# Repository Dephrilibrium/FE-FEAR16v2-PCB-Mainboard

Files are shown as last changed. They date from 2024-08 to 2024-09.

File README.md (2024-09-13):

# FEAR-Mainboard
This repository contains the KiCAD-design files of the F(ield) E(mission) A(rray) R(egulation) current control circuit board.

Note: This project is part of the SubModule-repository [FE-FEAR16v2][FE-FEAR16v2-SubmoduleRepo], where you can find sub-repositories for shield-PCBs and the firmware.

# Description
The board has two areas. A low-voltage side (5V USB for computer connection, top left) which is galvanically isolated up to 1500V from the high voltage side (rest of the PCB).

The board uses a USB-C jack on the low-voltage side of the board for communication. The USB-C can also be used as AC power supply, but for this, a USB-Hub with an AC-power adapter is recommended (depending on the amount of shields and their power-use). Alternatively, a 12V screw-terminal is added as option for an external 12V AC power supply. The option if 5V USB or 12V external supply is selected by a solder-jumper. (Note: +5V or +12V needs different DCDC converter types for the +-15V supply voltage on the high-voltage side!)

The board communicates via USB by providing a virtual COM-Port on the computer. The serial connection from the FT232 for board-internal communication is transferred from the low-voltage side to the high-voltage side via optocouplers and there connected to a TIVA-Launchpad, providing the microcontroller (µC). The Launchpad runs a terminal where you can query different commands e.g. querying measurement values, etc. The µC uses SPI connections for the ADCs and DACs.

ADCs and DACs have different supplies for logic (digital signals) and references (analog) and provide 2 ADC-inputs (VShnt0..15 and VDrp0..15) for measurements and 1x DAC-output (DAC0..15) for controls to each of the shields. Each ADC and DAC has only 8 inputs. Therefore, 2 of them each can be daisy-chained together to achieve 16 in-/outputs for VShnt, VDrp and DAC.

The ADC and DAC range is by default &pm;10V. However, the ranges can be adjusted within the firmware in the ADC/DAC-wrapper sourcecodes.

# Firmware
The board-firmware can be found in the [FE-FEAR16v2 Submodule-Repo][FE-FEAR16v2-SubmoduleRepo] and needs to be flashed onto the µC of the LaunchPad. Instructions and command-documentation can be found in the firmware-repository.

# Daisy-Chains
ADCs and DACs only have 8 In-/Outputs per chip. For enough In-/Outputs for up to 16 shields, 2 ADCs or DACs can be daisy-chained together. 1 and 2 chips per ADC- and DAC-chain were tested. When using only 1 chip per ADC-/DAC-chain, the MISO (SPI data in) and MOSI (SPI data out) pins of the empty ADC-footprint needs to be shorted. The connection is indicated by the silk-screen:
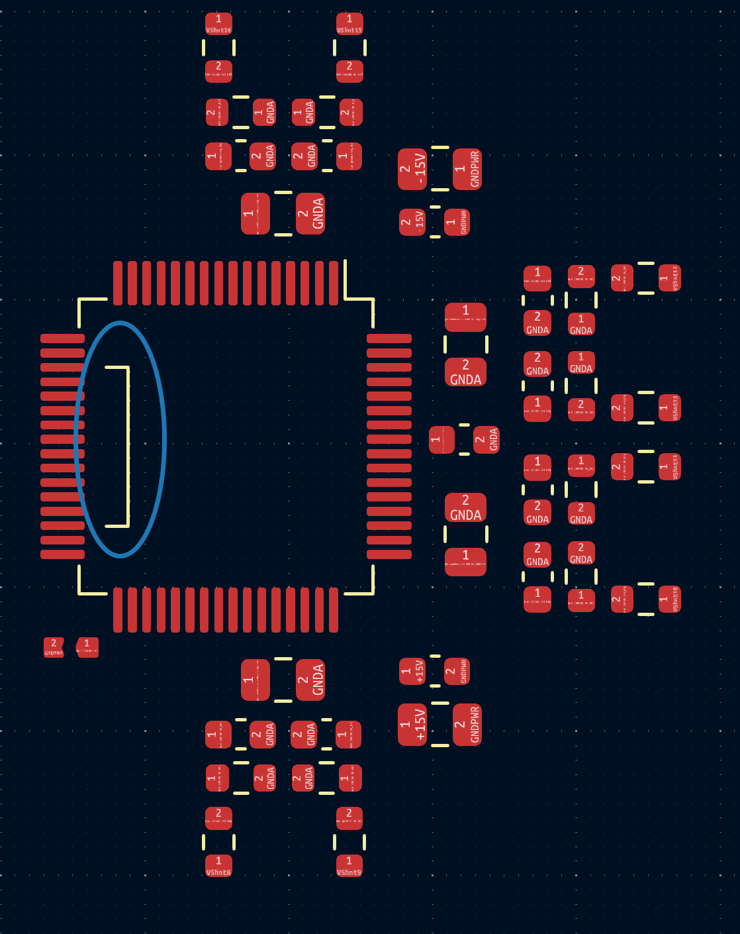
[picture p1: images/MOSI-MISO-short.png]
Principle of the regulation

The firmware handles this via software defines (described in the firmware-repository).

[FE-FEAR16v2-SubmoduleRepo]: https://github.com/Dephrilibrium/FE-FEAR16v2

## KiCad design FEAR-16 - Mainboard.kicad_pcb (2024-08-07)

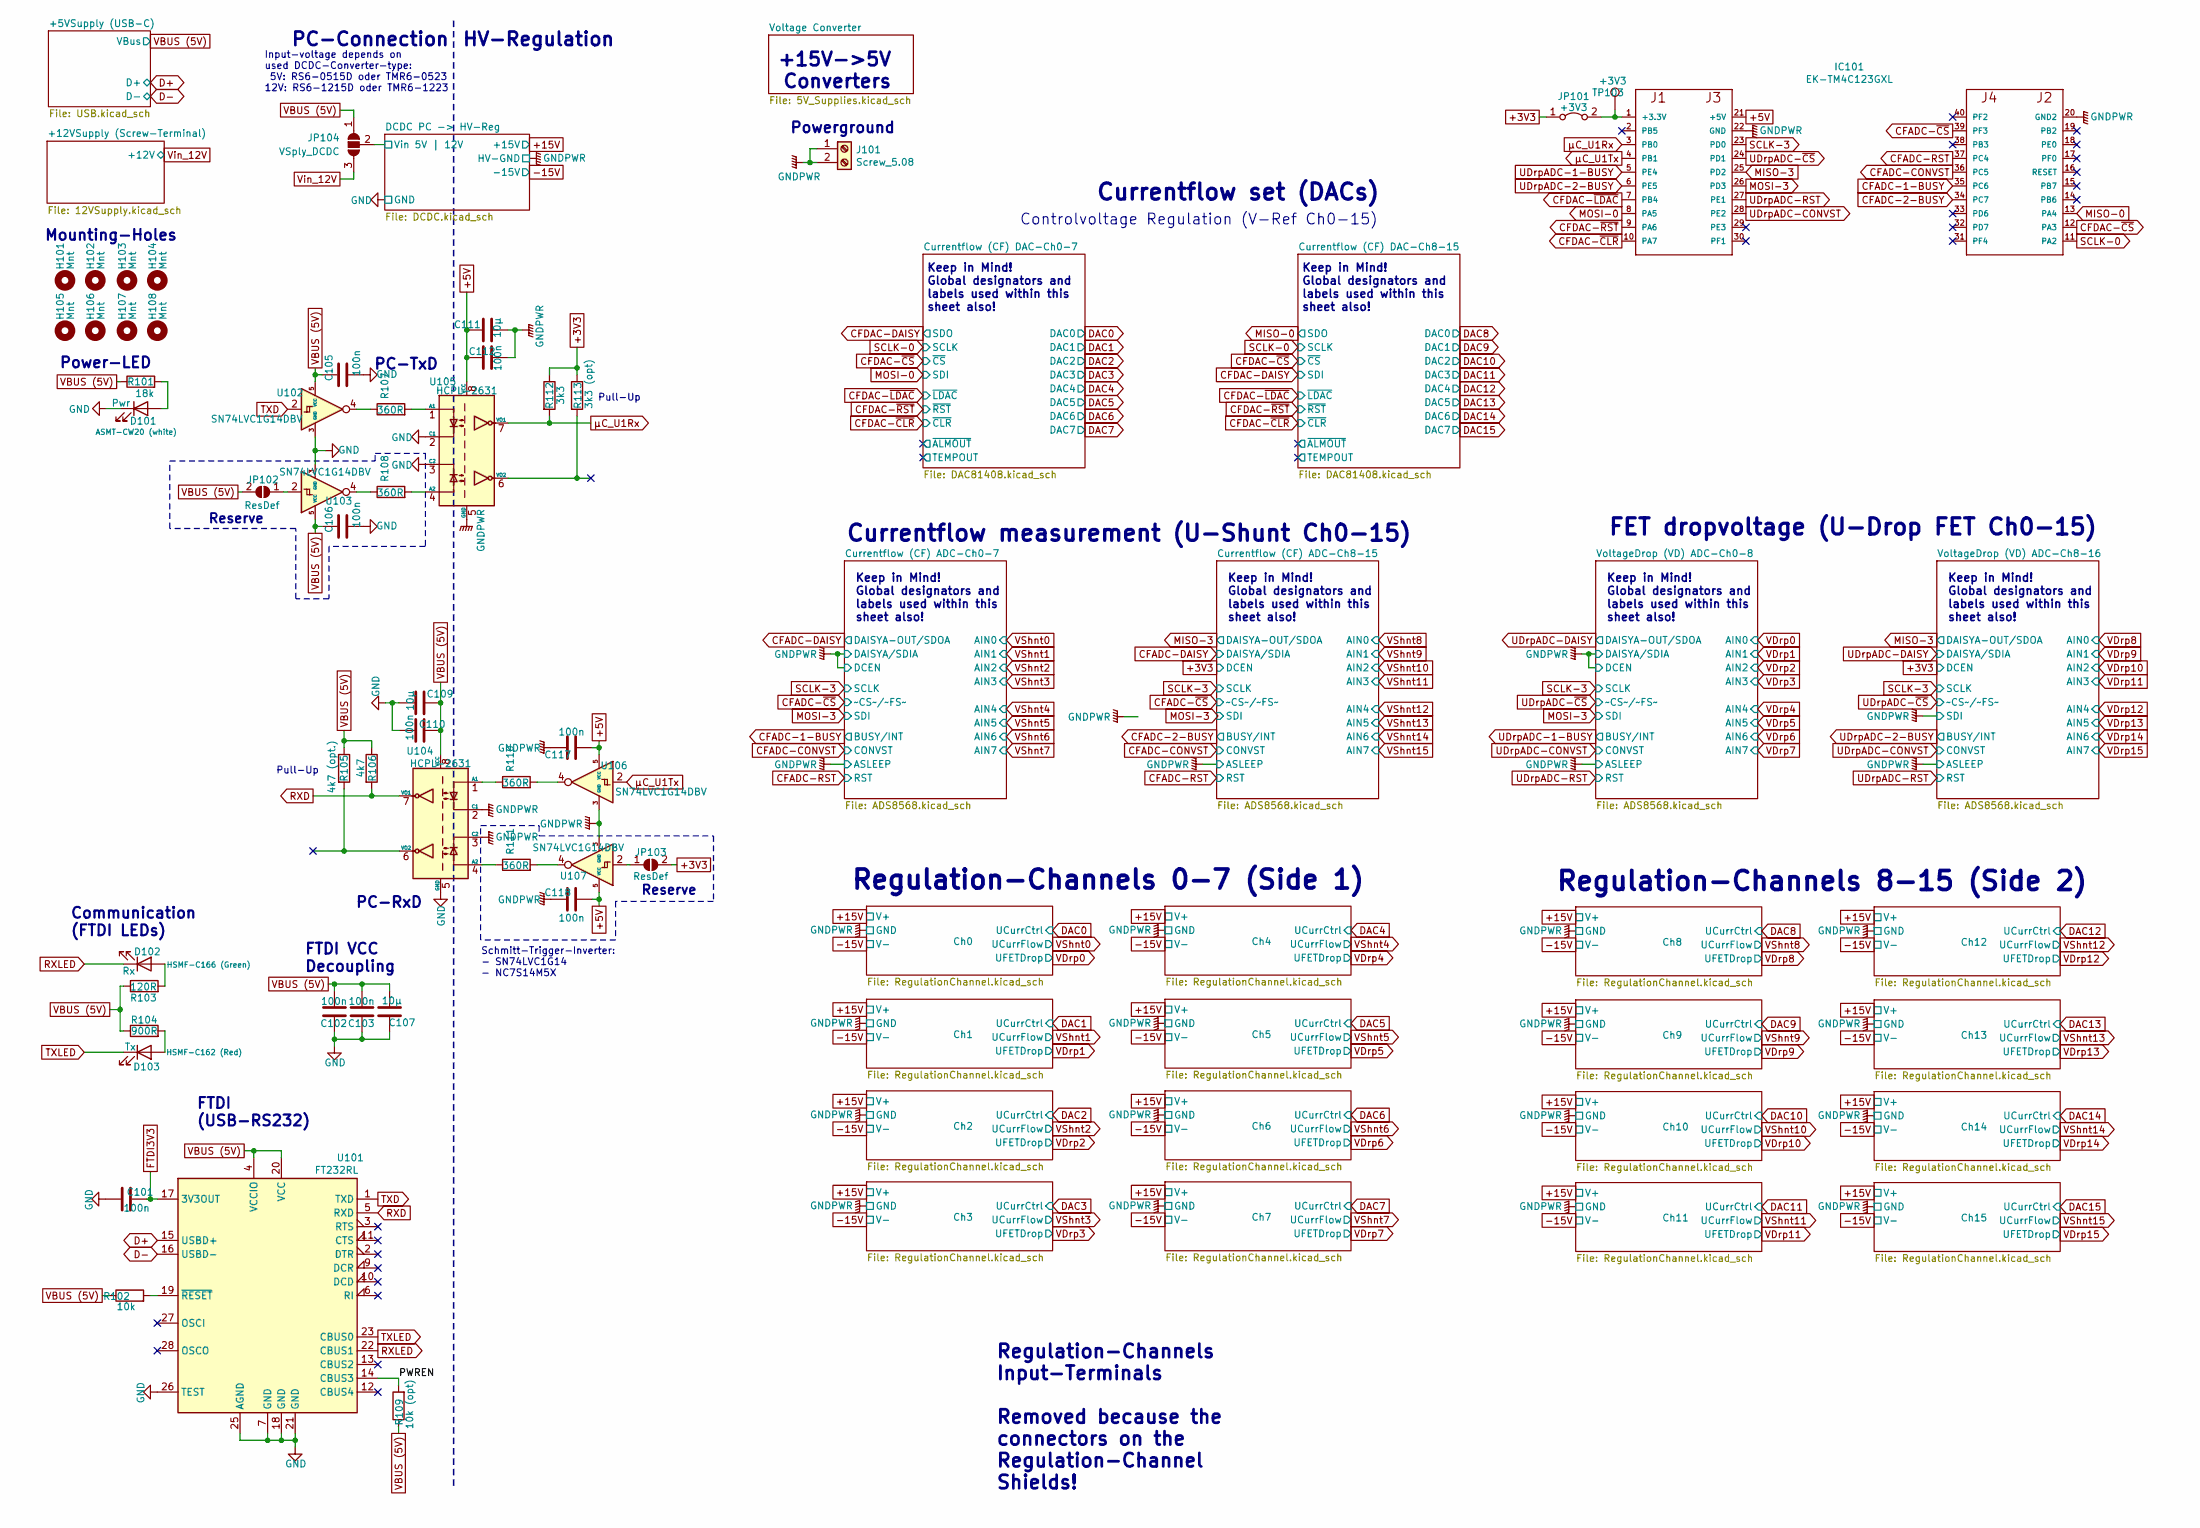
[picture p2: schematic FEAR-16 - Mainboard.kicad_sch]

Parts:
C101, C102, C103, C105, C106, C110, C112, C117, C118: 100n; C_0603_1608Metric
C107, C109, C111: 10µ; C_0805_2012Metric
D101: Pwr; LED_0603_1608Metric
D102: Rx; LED_0603_1608Metric
D103: Tx; LED_0603_1608Metric
H101, H102, H103, H104, H105, H106, H107, H108: Mnt; MountingHole_3.2mm_M3
IC101: EK-TM4C123GXL; TM4C123LAUNCHPAD
J101: Screw_5.08; TerminalBlock_RND_205-00232_1x02_P5.08mm_Horizontal
JP101: +3V3; PinHeader_1x02_P2.54mm_Vertical
JP102, JP103: ResDef; SolderJumper-2_P1.3mm_Open_RoundedPad1.0x1.5mm
JP104: VSply_DCDC; SolderJumper-3_P1.3mm_Open_RoundedPad1.0x1.5mm
R101: 18k; R_0603_1608Metric
R102: 10k; R_0603_1608Metric
R103: 120R; R_0603_1608Metric
R104: 900R; R_0603_1608Metric
R105: 4k7 (opt.); R_0603_1608Metric
R106: 4k7; R_0603_1608Metric
R107, R108, R110, R111: 360R; R_0603_1608Metric
R109: 10k (opt); R_0603_1608Metric
R112: 3k3; R_0603_1608Metric
R113: 3k3 (opt); R_0603_1608Metric
TP103: +3V3; TestPoint_Pad_D1.5mm
U101: FT232RL; SSOP-28_5.3x10.2mm_P0.65mm
U102, U103, U106, U107: SN74LVC1G14DBV; SOT-23-5
U104, U105: HCPL-2631; DIP-8_W7.62mm

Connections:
+3V3: JP101.1 (A), JP103.2 (B), R112.1, R113.1; also elsewhere on the board
+5V: C111.1, C112.2, C117.1, C118.1, IC101.21 (+5V), U105.8 (VCC), U106.5 (VCC), U107.5 (VCC); also elsewhere on the board
/DCDC PC -> HV-Reg/Vin 5V | 12V: JP104.2 (C); also elsewhere on the board
/PWREN: R109.2, U101.14 (CBUS3)
CFADC-1-BUSY: IC101.35 (PC6); also elsewhere on the board
CFADC-2-BUSY: IC101.34 (PC7); also elsewhere on the board
CFADC-CONVST: IC101.36 (PC5); also elsewhere on the board
CFADC-RST: IC101.37 (PC4); also elsewhere on the board
CFADC-~CS: IC101.39 (PF3); also elsewhere on the board
CFDAC-~CLR: IC101.10 (PA7); also elsewhere on the board
CFDAC-~CS: IC101.12 (PA3); also elsewhere on the board
CFDAC-~LDAC: IC101.7 (PB4); also elsewhere on the board
CFDAC-~RST: IC101.9 (PA6); also elsewhere on the board
D+: U101.15 (USBD+); also elsewhere on the board
D-: U101.16 (USBD-); also elsewhere on the board
FTDI3V3: C101.2, U101.17 (3V3OUT)
GND: C101.1, C102.1, C103.1, C105.2, C106.2, C107.2, C109.2, C110.1, D101.1 (K), U101.7 (GND), U101.18 (GND), U101.21 (GND), U101.25 (AGND), U101.26 (TEST), U102.3 (GND), U103.3 (GND), U104.5 (GND), U105.2 (C1), U105.3 (C2); also elsewhere on the board
GNDPWR: C111.2, C112.1, C117.2, C118.2, IC101.20 (GND2), IC101.22 (GND), J101.1, J101.2, U104.2 (C1), U104.3 (C2), U105.5 (GND), U106.3 (GND), U107.3 (GND); also elsewhere on the board
MISO-0: IC101.13 (PA4); also elsewhere on the board
MISO-3: IC101.25 (PD2); also elsewhere on the board
MOSI-0: IC101.8 (PA5); also elsewhere on the board
MOSI-3: IC101.26 (PD3); also elsewhere on the board
unnamed: D101.2 (A), R101.2
unnamed: D102.2 (A), R103.2
unnamed: D103.2 (A), R104.2
unnamed: IC101.1 (+3.3V), JP101.2 (B), TP103.1
unnamed: JP102.1 (A), U103.2
unnamed: JP103.1 (A), U107.2
unnamed: R107.1, U102.4
unnamed: R108.1, U103.4
unnamed: R110.2, U106.4
unnamed: R111.2, U107.4
unnamed: R102.2, U101.19 (~RESET)
unnamed: R110.1, U104.1 (A1)
unnamed: R111.1, U104.4 (A2)
unnamed: R107.2, U105.1 (A1)
unnamed: R108.2, U105.4 (A2)
RXD: R106.2, U101.5 (RXD), U104.7 (VO1)
RXLED: D102.1 (K), U101.22 (CBUS1)
SCLK-0: IC101.11 (PA2); also elsewhere on the board
SCLK-3: IC101.23 (PD0); also elsewhere on the board
TXD: U101.1 (TXD), U102.2
TXLED: D103.1 (K), U101.23 (CBUS0)
UDrpADC-1-BUSY: IC101.5 (PE4); also elsewhere on the board
UDrpADC-2-BUSY: IC101.6 (PE5); also elsewhere on the board
UDrpADC-CONVST: IC101.28 (PE2); also elsewhere on the board
UDrpADC-RST: IC101.27 (PE1); also elsewhere on the board
UDrpADC-~CS: IC101.24 (PD1); also elsewhere on the board
VBUS (5V): C102.2, C103.2, C105.1, C106.1, C107.1, C109.1, C110.2, JP102.2 (B), JP104.1 (A), R101.1, R102.1, R103.1, R104.1, R105.1, R106.1, R109.1, U101.4 (VCCIO), U101.20 (VCC), U102.5 (VCC), U103.5 (VCC), U104.8 (VCC); also elsewhere on the board
Vin_12V: JP104.3 (B); also elsewhere on the board
µC_U1Rx: IC101.3 (PB0), R112.2, U105.7 (VO1)
µC_U1Tx: IC101.4 (PB1), U106.2

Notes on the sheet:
Power-LED
Controlvoltage Regulation (V-Ref Ch0-15)
Keep in Mind! Global designators and labels used within this sheet also!
Reserve
Regulation-Channels 8-15 (Side 2)
Regulation-Channels Input-Terminals Removed because the connectors on the Regulation-Channel Shields!
Mounting-Holes
FTDI (USB-RS232)
HV-Regulation
PC-RxD
Input-voltage depends on used DCDC-Converter-type: 5V: RS6-0515D oder TMR6-0523 12V: RS6-1215D oder TMR6-1223
Communication (FTDI LEDs)
Regulation-Channels 0-7 (Side 1)
Pull-Up
Powerground
Currentflow measurement (U-Shunt Ch0-15)
FET dropvoltage (U-Drop FET Ch0-15)
PC-TxD
Currentflow set (DACs)
PC-Connection
+15V->5V Converters
Schmitt-Trigger-Inverter: - SN74LVC1G14 - NC7S14M5X
FTDI VCC Decoupling

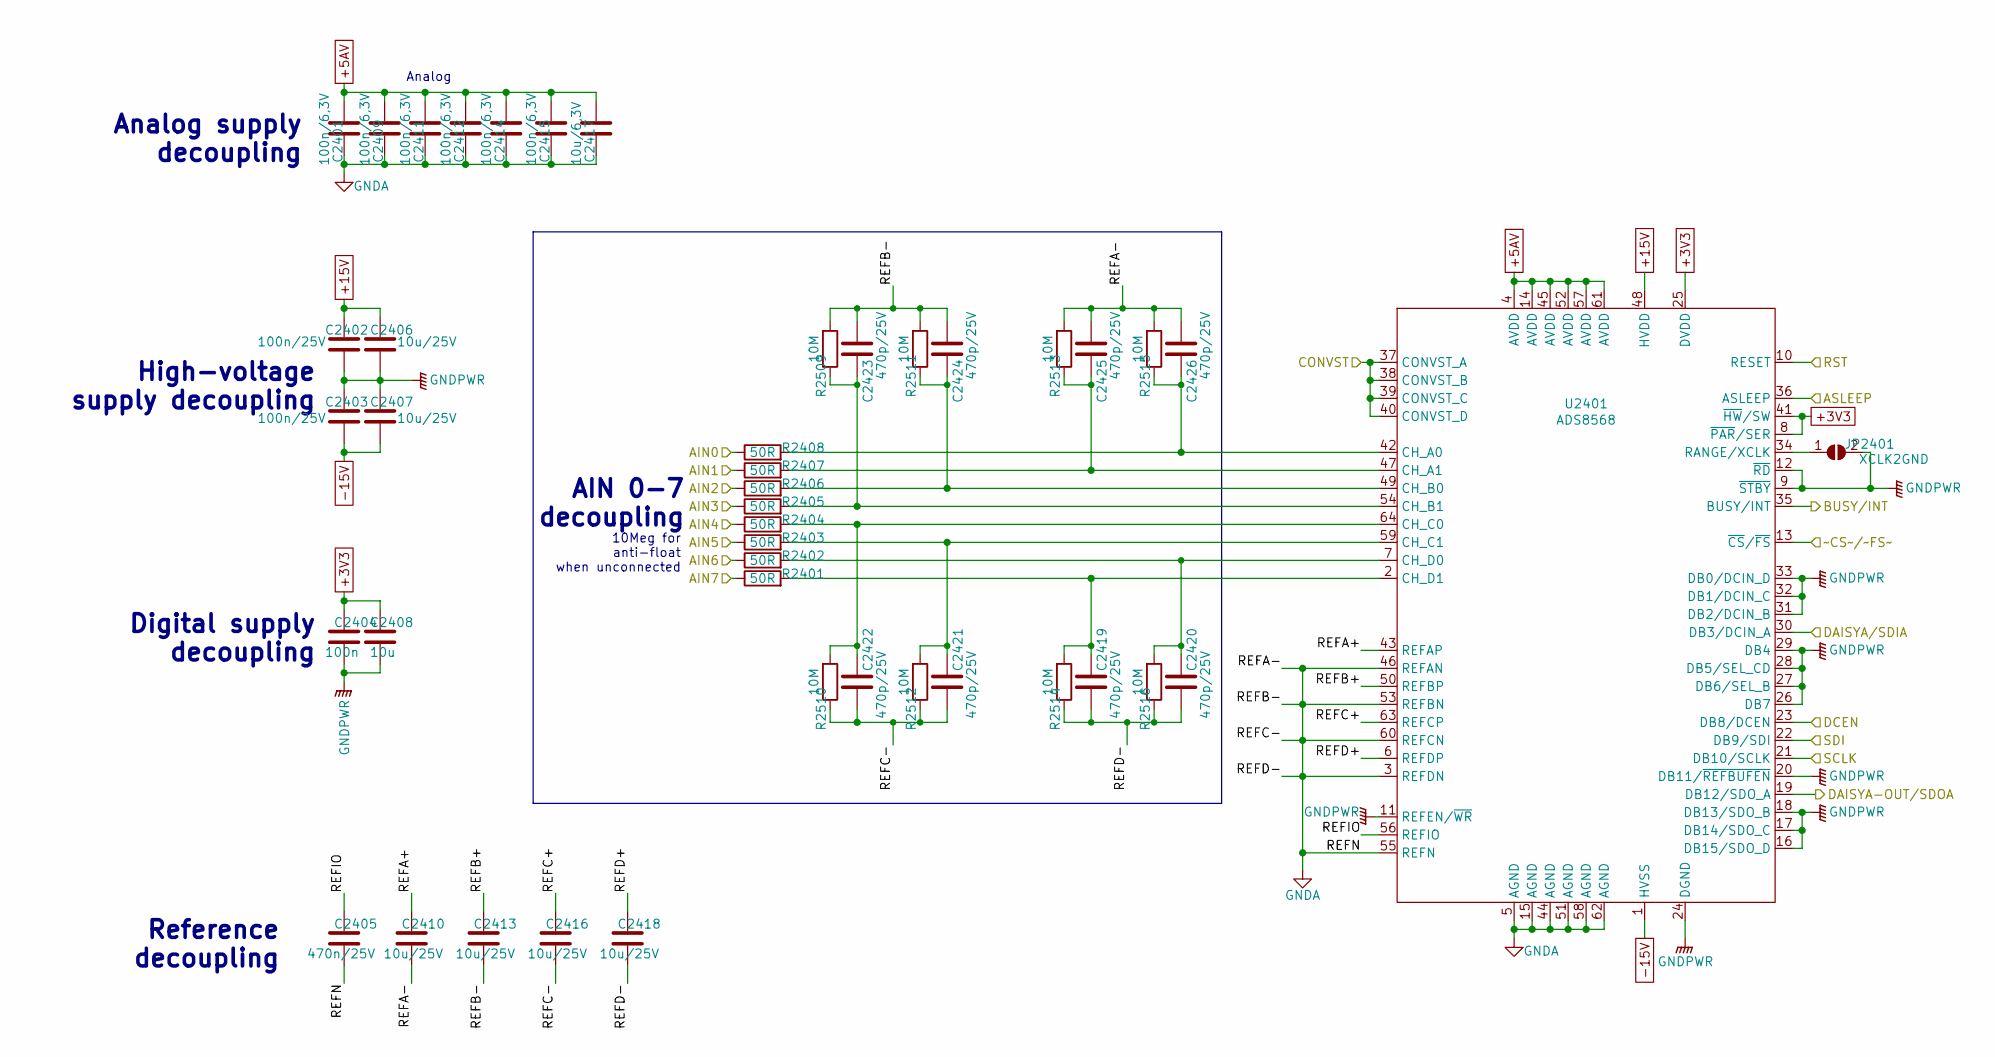
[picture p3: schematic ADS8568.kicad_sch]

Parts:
C2401, C2409, C2411, C2412, C2414, C2415: 100n/6,3V; C_0603_1608Metric
C2402, C2403: 100n/25V; C_0603_1608Metric
C2404: 100n; C_0603_1608Metric
C2405: 470n/25V; C_0603_1608Metric
C2406, C2407, C2410, C2413, C2416, C2418: 10u/25V; C_0805_2012Metric
C2408: 10u; C_0805_2012Metric
C2417: 10u/6,3V; C_0805_2012Metric
C2419, C2420, C2421, C2422, C2423, C2424, C2425, C2426: 470p/25V; C_0603_1608Metric
JP2401: XCLK2GND; Jumper_0.5x0.5
R2401, R2402, R2403, R2404, R2405, R2406, R2407, R2408: 50R; R_0603_1608Metric
R2509, R2510, R2511, R2512, R2513, R2514, R2515, R2516: 10M; R_0603_1608Metric
U2401: ADS8568; LQFP-64_10x10mm_P0.5mm

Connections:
+3V3: C2404.1, C2408.1, U2401.8 (~PAR/SER), U2401.25 (DVDD), U2401.41 (~HW/SW); also elsewhere on the board
+5AV: C2401.1, C2409.1, C2411.1, C2412.1, C2414.1, C2415.1, C2417.1, U2401.4 (AVDD), U2401.14 (AVDD), U2401.45 (AVDD), U2401.52 (AVDD), U2401.57 (AVDD), U2401.61 (AVDD); also elsewhere on the board
+15V: C2402.1, C2406.1, U2401.48 (HVDD); also elsewhere on the board
-15V: C2403.2, C2407.2, U2401.1 (HVSS); also elsewhere on the board
/VoltageDrop (VD) ADC-Ch0-8/REFA+: C2410.1, U2401.43 (REFAP)
/VoltageDrop (VD) ADC-Ch0-8/REFB+: C2413.1, U2401.50 (REFBP)
/VoltageDrop (VD) ADC-Ch0-8/REFC+: C2416.1, U2401.63 (REFCP)
/VoltageDrop (VD) ADC-Ch0-8/REFD+: C2418.1, U2401.6 (REFDP)
/VoltageDrop (VD) ADC-Ch0-8/REFIO: C2405.1, U2401.56 (REFIO)
GNDA: C2401.2, C2405.2, C2409.2, C2410.2, C2411.2, C2412.2, C2413.2, C2414.2, C2415.2, C2416.2, C2417.2, C2418.2, C2419.2, C2420.2, C2421.2, C2422.2, C2423.2, C2424.2, C2425.2, C2426.2, R2509.2, R2510.1, R2511.2, R2512.1, R2513.2, R2514.1, R2515.2, R2516.1, U2401.3 (REFDN), U2401.5 (AGND), U2401.15 (AGND), U2401.44 (AGND), U2401.46 (REFAN), U2401.51 (AGND), U2401.53 (REFBN), U2401.55 (REFN), U2401.58 (AGND), U2401.60 (REFCN), U2401.62 (AGND); also elsewhere on the board
GNDPWR: C2402.2, C2403.1, C2404.2, C2406.2, C2407.1, C2408.2, JP2401.2 (B), U2401.9 (~STBY), U2401.11 (REFEN/~WR), U2401.12 (~RD), U2401.16 (DB15/SDO_D), U2401.17 (DB14/SDO_C), U2401.18 (DB13/SDO_B), U2401.20 (DB11/~REFBUFEN), U2401.23 (DB8/DCEN), U2401.24 (DGND), U2401.26 (DB7), U2401.27 (DB6/SEL_B), U2401.28 (DB5/SEL_CD), U2401.29 (DB4), U2401.30 (DB3/DCIN_A), U2401.31 (DB2/DCIN_B), U2401.32 (DB1/DCIN_C), U2401.33 (DB0/DCIN_D), U2401.36 (ASLEEP); also elsewhere on the board
MOSI-3: U2401.22 (DB9/SDI); also elsewhere on the board
unnamed: JP2401.1 (A), U2401.34 (RANGE/XCLK)
unnamed: C2426.1, R2408.2, R2515.1, U2401.42 (CH_A0)
unnamed: C2425.1, R2407.2, R2513.1, U2401.47 (CH_A1)
unnamed: C2424.1, R2406.2, R2511.1, U2401.49 (CH_B0)
unnamed: C2423.1, R2405.2, R2509.1, U2401.54 (CH_B1)
unnamed: C2422.1, R2404.2, R2510.2, U2401.64 (CH_C0)
unnamed: C2421.1, R2403.2, R2512.2, U2401.59 (CH_C1)
unnamed: C2420.1, R2402.2, R2516.2, U2401.7 (CH_D0)
unnamed: C2419.1, R2401.2, R2514.2, U2401.2 (CH_D1)
SCLK-3: U2401.21 (DB10/SCLK); also elsewhere on the board
UDrpADC-1-BUSY: U2401.35 (BUSY/INT); also elsewhere on the board
UDrpADC-CONVST: U2401.37 (CONVST_A), U2401.38 (CONVST_B), U2401.39 (CONVST_C), U2401.40 (CONVST_D); also elsewhere on the board
UDrpADC-DAISY: U2401.19 (DB12/SDO_A); also elsewhere on the board
UDrpADC-RST: U2401.10 (RESET); also elsewhere on the board
UDrpADC-~CS: U2401.13 (~CS/~FS); also elsewhere on the board
VDrp0: R2408.1; also elsewhere on the board
VDrp1: R2407.1; also elsewhere on the board
VDrp2: R2406.1; also elsewhere on the board
VDrp3: R2405.1; also elsewhere on the board
VDrp4: R2404.1; also elsewhere on the board
VDrp5: R2403.1; also elsewhere on the board
VDrp6: R2402.1; also elsewhere on the board
VDrp7: R2401.1; also elsewhere on the board

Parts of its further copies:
C1301, C1309, C1311, C1312, C1314, C1315, C2201, C2209, C2211, C2212, C2214, C2215, C2501, C2509, C2511, C2512, C2514, C2515: 100n/6,3V; C_0603_1608Metric
C1302, C1303, C2202, C2203, C2502, C2503: 100n/25V; C_0603_1608Metric
C1304, C2204, C2504: 100n; C_0603_1608Metric
C1305, C2205, C2505: 470n/25V; C_0603_1608Metric
C1306, C1307, C1310, C1313, C1316, C1318, C2206, C2207, C2210, C2213, C2216, C2218, C2506, C2507, C2510, C2513, C2516, C2518: 10u/25V; C_0805_2012Metric
C1308, C2208, C2508: 10u; C_0805_2012Metric
C1317, C2217, C2517: 10u/6,3V; C_0805_2012Metric
C1319, C1320, C1321, C1322, C1323, C1324, C1325, C1326, C2219, C2220, C2221, C2222, C2223, C2224, C2225, C2226, C2519, C2520, C2521, C2522, C2523, C2524, C2525, C2526: 470p/25V; C_0603_1608Metric
JP1301, JP2201, JP2501: XCLK2GND; Jumper_0.5x0.5
R1301, R1302, R1303, R1304, R1305, R1306, R1307, R1308, R2201, R2202, R2203, R2204, R2205, R2206, R2207, R2208, R2501, R2502, R2503, R2504, R2505, R2506, R2507, R2508: 50R; R_0603_1608Metric
R1309, R1310, R1311, R1312, R1313, R1314, R1315, R1316, R2302, R2303, R2304, R2305, R2306, R2307, R2308, R2309, R2601, R2602, R2603, R2604, R2605, R2606, R2607, R2608: 10M; R_0603_1608Metric
U1301, U2201, U2501: ADS8568; LQFP-64_10x10mm_P0.5mm

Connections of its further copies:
+3V3: C1304.1, C1308.1, C2204.1, C2208.1, C2504.1, C2508.1, U1301.8 (~PAR/SER), U1301.25 (DVDD), U1301.41 (~HW/SW), U2201.8 (~PAR/SER), U2201.23 (DB8/DCEN), U2201.25 (DVDD), U2201.41 (~HW/SW), U2501.8 (~PAR/SER), U2501.23 (DB8/DCEN), U2501.25 (DVDD), U2501.41 (~HW/SW); also elsewhere on the board
+5AV: C1301.1, C1309.1, C1311.1, C1312.1, C1314.1, C1315.1, C1317.1, C2201.1, C2209.1, C2211.1, C2212.1, C2214.1, C2215.1, C2217.1, C2501.1, C2509.1, C2511.1, C2512.1, C2514.1, C2515.1, C2517.1, U1301.4 (AVDD), U1301.14 (AVDD), U1301.45 (AVDD), U1301.52 (AVDD), U1301.57 (AVDD), U1301.61 (AVDD), U2201.4 (AVDD), U2201.14 (AVDD), U2201.45 (AVDD), U2201.52 (AVDD), U2201.57 (AVDD), U2201.61 (AVDD), U2501.4 (AVDD), U2501.14 (AVDD), U2501.45 (AVDD), U2501.52 (AVDD), U2501.57 (AVDD), U2501.61 (AVDD); also elsewhere on the board
+15V: C1302.1, C1306.1, C2202.1, C2206.1, C2502.1, C2506.1, U1301.48 (HVDD), U2201.48 (HVDD), U2501.48 (HVDD); also elsewhere on the board
-15V: C1303.2, C1307.2, C2203.2, C2207.2, C2503.2, C2507.2, U1301.1 (HVSS), U2201.1 (HVSS), U2501.1 (HVSS); also elsewhere on the board
/Currentflow (CF) ADC-Ch0-7/REFA+: C1310.1, U1301.43 (REFAP)
/Currentflow (CF) ADC-Ch0-7/REFB+: C1313.1, U1301.50 (REFBP)
/Currentflow (CF) ADC-Ch0-7/REFC+: C1316.1, U1301.63 (REFCP)
/Currentflow (CF) ADC-Ch0-7/REFD+: C1318.1, U1301.6 (REFDP)
/Currentflow (CF) ADC-Ch0-7/REFIO: C1305.1, U1301.56 (REFIO)
/Currentflow (CF) ADC-Ch8-15/REFA+: C2210.1, U2201.43 (REFAP)
/Currentflow (CF) ADC-Ch8-15/REFB+: C2213.1, U2201.50 (REFBP)
/Currentflow (CF) ADC-Ch8-15/REFC+: C2216.1, U2201.63 (REFCP)
/Currentflow (CF) ADC-Ch8-15/REFD+: C2218.1, U2201.6 (REFDP)
/Currentflow (CF) ADC-Ch8-15/REFIO: C2205.1, U2201.56 (REFIO)
/Currentflow (CF) ADC-Ch8-15/SDI: U2201.22 (DB9/SDI)
/VoltageDrop (VD) ADC-Ch8-16/REFA+: C2510.1, U2501.43 (REFAP)
/VoltageDrop (VD) ADC-Ch8-16/REFB+: C2513.1, U2501.50 (REFBP)
/VoltageDrop (VD) ADC-Ch8-16/REFC+: C2516.1, U2501.63 (REFCP)
/VoltageDrop (VD) ADC-Ch8-16/REFD+: C2518.1, U2501.6 (REFDP)
/VoltageDrop (VD) ADC-Ch8-16/REFIO: C2505.1, U2501.56 (REFIO)
CFADC-1-BUSY: U1301.35 (BUSY/INT); also elsewhere on the board
CFADC-2-BUSY: U2201.35 (BUSY/INT); also elsewhere on the board
CFADC-CONVST: U1301.37 (CONVST_A), U1301.38 (CONVST_B), U1301.39 (CONVST_C), U1301.40 (CONVST_D), U2201.37 (CONVST_A), U2201.38 (CONVST_B), U2201.39 (CONVST_C), U2201.40 (CONVST_D); also elsewhere on the board
CFADC-DAISY: U1301.19 (DB12/SDO_A), U2201.30 (DB3/DCIN_A)
CFADC-RST: U1301.10 (RESET), U2201.10 (RESET); also elsewhere on the board
CFADC-~CS: U1301.13 (~CS/~FS), U2201.13 (~CS/~FS); also elsewhere on the board
GNDA: C1301.2, C1305.2, C1309.2, C1310.2, C1311.2, C1312.2, C1313.2, C1314.2, C1315.2, C1316.2, C1317.2, C1318.2, C1319.2, C1320.2, C1321.2, C1322.2, C1323.2, C1324.2, C1325.2, C1326.2, C2201.2, C2205.2, C2209.2, C2210.2, C2211.2, C2212.2, C2213.2, C2214.2, C2215.2, C2216.2, C2217.2, C2218.2, C2219.2, C2220.2, C2221.2, C2222.2, C2223.2, C2224.2, C2225.2, C2226.2, C2501.2, C2505.2, C2509.2, C2510.2, C2511.2, C2512.2, C2513.2, C2514.2, C2515.2, C2516.2, C2517.2, C2518.2, C2519.2, C2520.2, C2521.2, C2522.2, C2523.2, C2524.2, C2525.2, C2526.2, R1309.2, R1310.1, R1311.2, R1312.1, R1313.2, R1314.1, R1315.2, R1316.1, R2302.2, R2303.1, R2304.2, R2305.1, R2306.2, R2307.1, R2308.2, R2309.1, R2601.2, R2602.1, R2603.2, R2604.1, R2605.2, R2606.1, R2607.2, R2608.1, U1301.3 (REFDN), U1301.5 (AGND), U1301.15 (AGND), U1301.44 (AGND), U1301.46 (REFAN), U1301.51 (AGND), U1301.53 (REFBN), U1301.55 (REFN), U1301.58 (AGND), U1301.60 (REFCN), U1301.62 (AGND), U2201.3 (REFDN), U2201.5 (AGND), U2201.15 (AGND), U2201.44 (AGND), U2201.46 (REFAN), U2201.51 (AGND), U2201.53 (REFBN), U2201.55 (REFN), U2201.58 (AGND), U2201.60 (REFCN), U2201.62 (AGND), U2501.3 (REFDN), U2501.5 (AGND), U2501.15 (AGND), U2501.44 (AGND), U2501.46 (REFAN), U2501.51 (AGND), U2501.53 (REFBN), U2501.55 (REFN), U2501.58 (AGND), U2501.60 (REFCN), U2501.62 (AGND); also elsewhere on the board
GNDPWR: C1302.2, C1303.1, C1304.2, C1306.2, C1307.1, C1308.2, C2202.2, C2203.1, C2204.2, C2206.2, C2207.1, C2208.2, C2502.2, C2503.1, C2504.2, C2506.2, C2507.1, C2508.2, JP1301.2 (B), JP2201.2 (B), JP2501.2 (B), U1301.9 (~STBY), U1301.11 (REFEN/~WR), U1301.12 (~RD), U1301.16 (DB15/SDO_D), U1301.17 (DB14/SDO_C), U1301.18 (DB13/SDO_B), U1301.20 (DB11/~REFBUFEN), U1301.23 (DB8/DCEN), U1301.24 (DGND), U1301.26 (DB7), U1301.27 (DB6/SEL_B), U1301.28 (DB5/SEL_CD), U1301.29 (DB4), U1301.30 (DB3/DCIN_A), U1301.31 (DB2/DCIN_B), U1301.32 (DB1/DCIN_C), U1301.33 (DB0/DCIN_D), U1301.36 (ASLEEP), U2201.9 (~STBY), U2201.11 (REFEN/~WR), U2201.12 (~RD), U2201.16 (DB15/SDO_D), U2201.17 (DB14/SDO_C), U2201.18 (DB13/SDO_B), U2201.20 (DB11/~REFBUFEN), U2201.24 (DGND), U2201.26 (DB7), U2201.27 (DB6/SEL_B), U2201.28 (DB5/SEL_CD), U2201.29 (DB4), U2201.31 (DB2/DCIN_B), U2201.32 (DB1/DCIN_C), U2201.33 (DB0/DCIN_D), U2201.36 (ASLEEP), U2501.9 (~STBY), U2501.11 (REFEN/~WR), U2501.12 (~RD), U2501.16 (DB15/SDO_D), U2501.17 (DB14/SDO_C), U2501.18 (DB13/SDO_B), U2501.20 (DB11/~REFBUFEN), U2501.22 (DB9/SDI), U2501.24 (DGND), U2501.26 (DB7), U2501.27 (DB6/SEL_B), U2501.28 (DB5/SEL_CD), U2501.29 (DB4), U2501.31 (DB2/DCIN_B), U2501.32 (DB1/DCIN_C), U2501.33 (DB0/DCIN_D), U2501.36 (ASLEEP); also elsewhere on the board
MISO-3: U2201.19 (DB12/SDO_A), U2501.19 (DB12/SDO_A); also elsewhere on the board
MOSI-3: U1301.22 (DB9/SDI); also elsewhere on the board
unnamed: JP1301.1 (A), U1301.34 (RANGE/XCLK)
unnamed: JP2201.1 (A), U2201.34 (RANGE/XCLK)
unnamed: JP2501.1 (A), U2501.34 (RANGE/XCLK)
unnamed: C1326.1, R1308.2, R1315.1, U1301.42 (CH_A0)
unnamed: C1325.1, R1307.2, R1313.1, U1301.47 (CH_A1)
unnamed: C1324.1, R1306.2, R1311.1, U1301.49 (CH_B0)
unnamed: C1323.1, R1305.2, R1309.1, U1301.54 (CH_B1)
unnamed: C1322.1, R1304.2, R1310.2, U1301.64 (CH_C0)
unnamed: C1321.1, R1303.2, R1312.2, U1301.59 (CH_C1)
unnamed: C1320.1, R1302.2, R1316.2, U1301.7 (CH_D0)
unnamed: C1319.1, R1301.2, R1314.2, U1301.2 (CH_D1)
unnamed: C2226.1, R2208.2, R2308.1, U2201.42 (CH_A0)
unnamed: C2225.1, R2207.2, R2306.1, U2201.47 (CH_A1)
unnamed: C2224.1, R2206.2, R2304.1, U2201.49 (CH_B0)
unnamed: C2223.1, R2205.2, R2302.1, U2201.54 (CH_B1)
unnamed: C2222.1, R2204.2, R2303.2, U2201.64 (CH_C0)
unnamed: C2221.1, R2203.2, R2305.2, U2201.59 (CH_C1)
unnamed: C2220.1, R2202.2, R2309.2, U2201.7 (CH_D0)
unnamed: C2219.1, R2201.2, R2307.2, U2201.2 (CH_D1)
unnamed: C2526.1, R2508.2, R2607.1, U2501.42 (CH_A0)
unnamed: C2525.1, R2507.2, R2605.1, U2501.47 (CH_A1)
unnamed: C2524.1, R2506.2, R2603.1, U2501.49 (CH_B0)
unnamed: C2523.1, R2505.2, R2601.1, U2501.54 (CH_B1)
unnamed: C2522.1, R2504.2, R2602.2, U2501.64 (CH_C0)
unnamed: C2521.1, R2503.2, R2604.2, U2501.59 (CH_C1)
unnamed: C2520.1, R2502.2, R2608.2, U2501.7 (CH_D0)
unnamed: C2519.1, R2501.2, R2606.2, U2501.2 (CH_D1)
SCLK-3: U1301.21 (DB10/SCLK), U2201.21 (DB10/SCLK), U2501.21 (DB10/SCLK); also elsewhere on the board
UDrpADC-2-BUSY: U2501.35 (BUSY/INT); also elsewhere on the board
UDrpADC-CONVST: U2501.37 (CONVST_A), U2501.38 (CONVST_B), U2501.39 (CONVST_C), U2501.40 (CONVST_D); also elsewhere on the board
UDrpADC-DAISY: U2501.30 (DB3/DCIN_A); also elsewhere on the board
UDrpADC-RST: U2501.10 (RESET); also elsewhere on the board
UDrpADC-~CS: U2501.13 (~CS/~FS); also elsewhere on the board
VDrp8: R2508.1; also elsewhere on the board
VDrp9: R2507.1; also elsewhere on the board
VDrp10: R2506.1; also elsewhere on the board
VDrp11: R2505.1; also elsewhere on the board
VDrp12: R2504.1; also elsewhere on the board
VDrp13: R2503.1; also elsewhere on the board
VDrp14: R2502.1; also elsewhere on the board
VDrp15: R2501.1; also elsewhere on the board
VShnt0: R1308.1; also elsewhere on the board
VShnt1: R1307.1; also elsewhere on the board
VShnt2: R1306.1; also elsewhere on the board
VShnt3: R1305.1; also elsewhere on the board
VShnt4: R1304.1; also elsewhere on the board
VShnt5: R1303.1; also elsewhere on the board
VShnt6: R1302.1; also elsewhere on the board
VShnt7: R1301.1; also elsewhere on the board
VShnt8: R2208.1; also elsewhere on the board
VShnt9: R2207.1; also elsewhere on the board
VShnt10: R2206.1; also elsewhere on the board
VShnt11: R2205.1; also elsewhere on the board
VShnt12: R2204.1; also elsewhere on the board
VShnt13: R2203.1; also elsewhere on the board
VShnt14: R2202.1; also elsewhere on the board
VShnt15: R2201.1; also elsewhere on the board

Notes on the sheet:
Analog
High-voltage supply decoupling
AIN 0-7 decoupling
10Meg for anti-float when unconnected
Reference decoupling
Digital supply decoupling
Analog supply decoupling

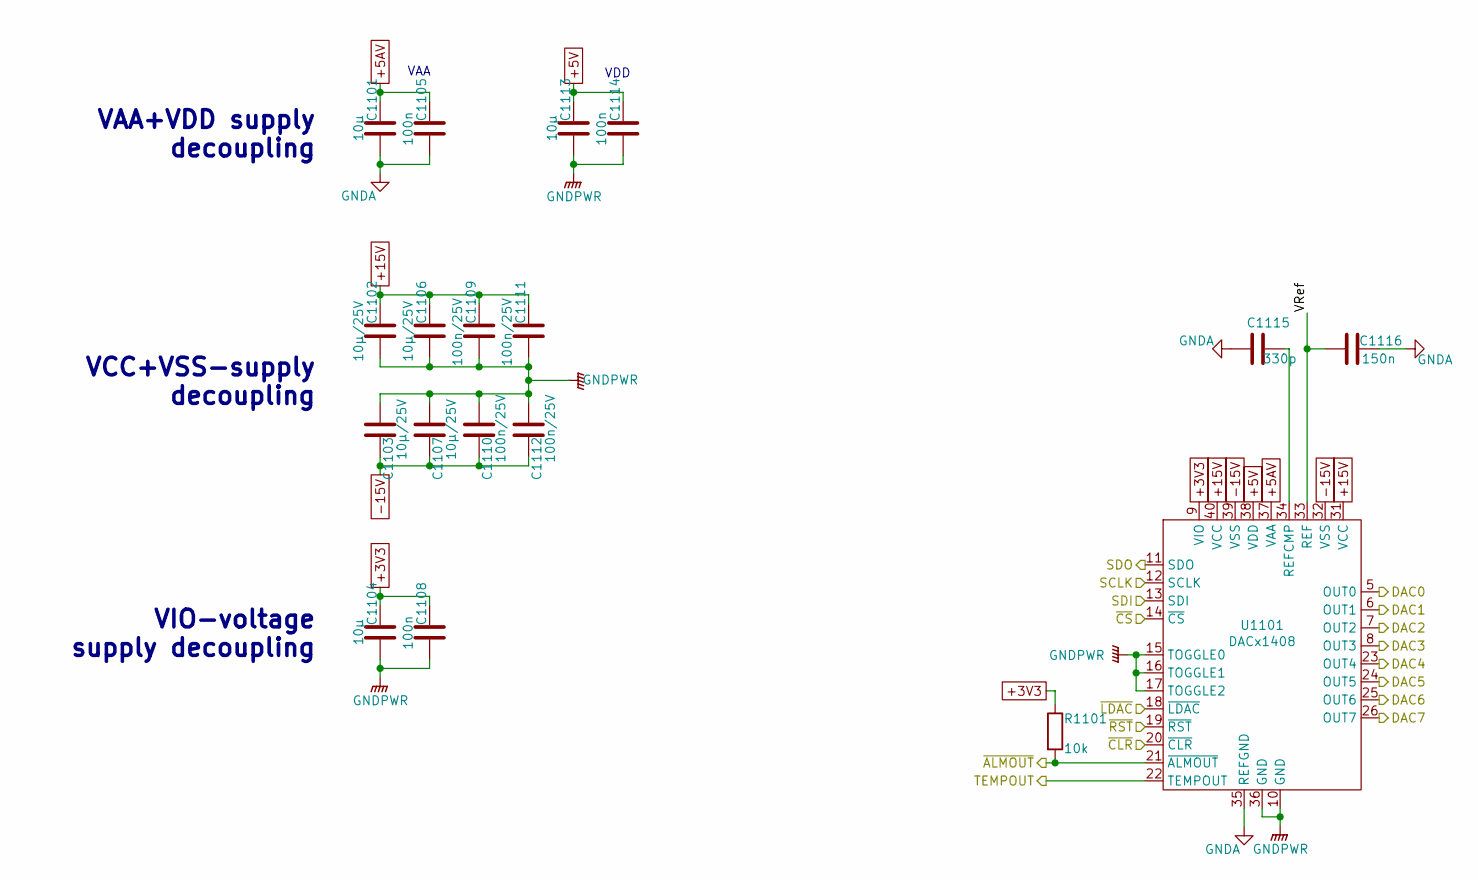
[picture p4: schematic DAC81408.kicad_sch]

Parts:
C1101, C1104, C1113: 10µ; C_0805_2012Metric
C1102, C1103, C1106, C1107: 10µ/25V; C_0805_2012Metric
C1105, C1108, C1114: 100n; C_0603_1608Metric
C1109, C1110, C1111, C1112: 100n/25V; C_0603_1608Metric
C1115: 330p; C_0603_1608Metric
C1116: 150n; C_0603_1608Metric
R1101: 10k; R_0603_1608Metric
U1101: DACx1408; HVQFN-40-1EP_6x6mm_P0.5mm_EP4.1x4.1mm_ThermalVias

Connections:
+3V3: C1104.1, C1108.1, R1101.1, U1101.9 (VIO); also elsewhere on the board
+5AV: C1101.1, C1105.1, U1101.37 (VAA); also elsewhere on the board
+5V: C1113.1, C1114.1, U1101.38 (VDD); also elsewhere on the board
+15V: C1102.1, C1106.1, C1109.1, C1111.1, U1101.31 (VCC), U1101.40 (VCC); also elsewhere on the board
-15V: C1103.1, C1107.1, C1110.1, C1112.1, U1101.32 (VSS), U1101.39 (VSS); also elsewhere on the board
/Currentflow (CF) DAC-Ch0-7/TEMPOUT: U1101.22 (TEMPOUT)
/Currentflow (CF) DAC-Ch0-7/VRef: C1116.2, U1101.33 (REF)
/Currentflow (CF) DAC-Ch0-7/~ALMOUT: R1101.2, U1101.21 (~ALMOUT)
CFDAC-DAISY: U1101.11 (SDO); also elsewhere on the board
CFDAC-~CLR: U1101.20 (~CLR); also elsewhere on the board
CFDAC-~CS: U1101.14 (~CS); also elsewhere on the board
CFDAC-~LDAC: U1101.18 (~LDAC); also elsewhere on the board
CFDAC-~RST: U1101.19 (~RST); also elsewhere on the board
DAC0: U1101.5 (OUT0); also elsewhere on the board
DAC1: U1101.6 (OUT1); also elsewhere on the board
DAC2: U1101.7 (OUT2); also elsewhere on the board
DAC3: U1101.8 (OUT3); also elsewhere on the board
DAC4: U1101.23 (OUT4); also elsewhere on the board
DAC5: U1101.24 (OUT5); also elsewhere on the board
DAC6: U1101.25 (OUT6); also elsewhere on the board
DAC7: U1101.26 (OUT7); also elsewhere on the board
GNDA: C1101.2, C1105.2, C1115.2, C1116.1, U1101.35 (REFGND); also elsewhere on the board
GNDPWR: C1102.2, C1103.2, C1104.2, C1106.2, C1107.2, C1108.2, C1109.2, C1110.2, C1111.2, C1112.2, C1113.2, C1114.2, U1101.10 (GND), U1101.15 (TOGGLE0), U1101.16 (TOGGLE1), U1101.17 (TOGGLE2), U1101.36 (GND); also elsewhere on the board
MOSI-0: U1101.13 (SDI); also elsewhere on the board
unnamed: C1115.1, U1101.34 (REFCMP)
SCLK-0: U1101.12 (SCLK); also elsewhere on the board

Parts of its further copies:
C2301, C2304, C2313: 10µ; C_0805_2012Metric
C2302, C2303, C2306, C2307: 10µ/25V; C_0805_2012Metric
C2305, C2308, C2314: 100n; C_0603_1608Metric
C2309, C2310, C2311, C2312: 100n/25V; C_0603_1608Metric
C2315: 330p; C_0603_1608Metric
C2316: 150n; C_0603_1608Metric
R2301: 10k; R_0603_1608Metric
U2301: DACx1408; HVQFN-40-1EP_6x6mm_P0.5mm_EP4.1x4.1mm_ThermalVias

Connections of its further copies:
+3V3: C2304.1, C2308.1, R2301.1, U2301.9 (VIO); also elsewhere on the board
+5AV: C2301.1, C2305.1, U2301.37 (VAA); also elsewhere on the board
+5V: C2313.1, C2314.1, U2301.38 (VDD); also elsewhere on the board
+15V: C2302.1, C2306.1, C2309.1, C2311.1, U2301.31 (VCC), U2301.40 (VCC); also elsewhere on the board
-15V: C2303.1, C2307.1, C2310.1, C2312.1, U2301.32 (VSS), U2301.39 (VSS); also elsewhere on the board
/Currentflow (CF) DAC-Ch8-15/TEMPOUT: U2301.22 (TEMPOUT)
/Currentflow (CF) DAC-Ch8-15/VRef: C2316.2, U2301.33 (REF)
/Currentflow (CF) DAC-Ch8-15/~ALMOUT: R2301.2, U2301.21 (~ALMOUT)
CFDAC-DAISY: U2301.13 (SDI); also elsewhere on the board
CFDAC-~CLR: U2301.20 (~CLR); also elsewhere on the board
CFDAC-~CS: U2301.14 (~CS); also elsewhere on the board
CFDAC-~LDAC: U2301.18 (~LDAC); also elsewhere on the board
CFDAC-~RST: U2301.19 (~RST); also elsewhere on the board
DAC8: U2301.5 (OUT0); also elsewhere on the board
DAC9: U2301.6 (OUT1); also elsewhere on the board
DAC10: U2301.7 (OUT2); also elsewhere on the board
DAC11: U2301.8 (OUT3); also elsewhere on the board
DAC12: U2301.23 (OUT4); also elsewhere on the board
DAC13: U2301.24 (OUT5); also elsewhere on the board
DAC14: U2301.25 (OUT6); also elsewhere on the board
DAC15: U2301.26 (OUT7); also elsewhere on the board
GNDA: C2301.2, C2305.2, C2315.2, C2316.1, U2301.35 (REFGND); also elsewhere on the board
GNDPWR: C2302.2, C2303.2, C2304.2, C2306.2, C2307.2, C2308.2, C2309.2, C2310.2, C2311.2, C2312.2, C2313.2, C2314.2, U2301.10 (GND), U2301.15 (TOGGLE0), U2301.16 (TOGGLE1), U2301.17 (TOGGLE2), U2301.36 (GND); also elsewhere on the board
MISO-0: U2301.11 (SDO); also elsewhere on the board
unnamed: C2315.1, U2301.34 (REFCMP)
SCLK-0: U2301.12 (SCLK); also elsewhere on the board

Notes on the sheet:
VDD
VIO-voltage supply decoupling
VAA
VAA+VDD supply decoupling
VCC+VSS-supply decoupling

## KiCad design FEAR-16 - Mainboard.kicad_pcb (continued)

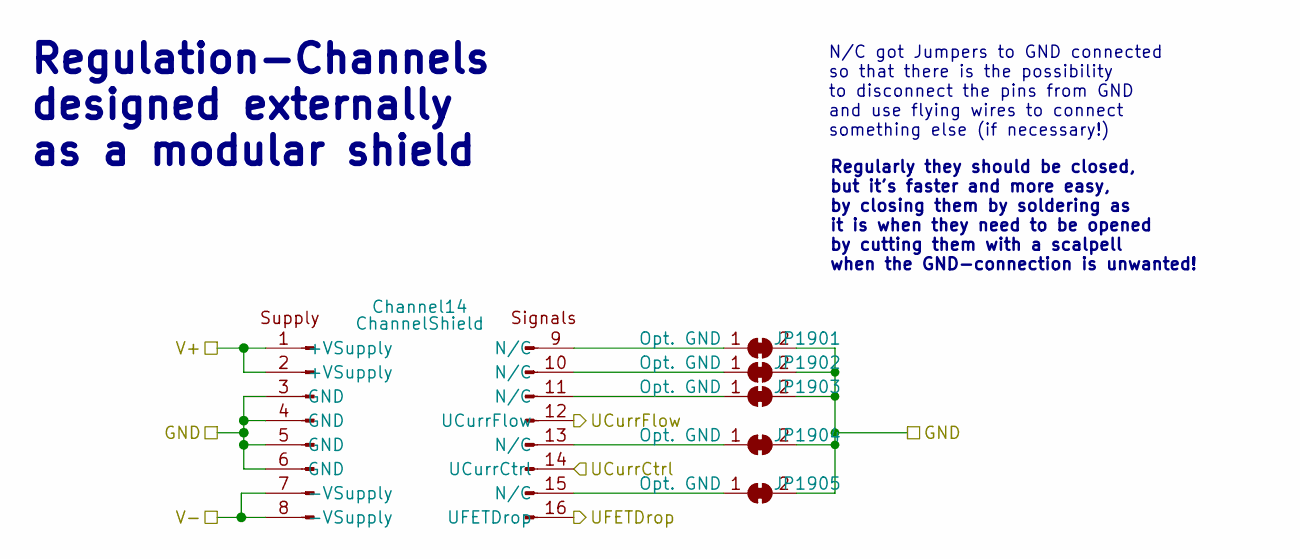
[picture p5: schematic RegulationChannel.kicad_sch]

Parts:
Channel14: ChannelShield
JP1901, JP1902, JP1903, JP1904, JP1905: Opt. GND; SolderJumper-2_P1.3mm_Open_RoundedPad1.0x1.5mm

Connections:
+15V: Channel14.1 (+VSupply), Channel14.2 (+VSupply); also elsewhere on the board
-15V: Channel14.7 (-VSupply), Channel14.8 (-VSupply); also elsewhere on the board
DAC14: Channel14.14 (UCurrCtrl); also elsewhere on the board
GNDPWR: Channel14.3 (GND), Channel14.4 (GND), Channel14.5 (GND), Channel14.6 (GND), JP1901.2 (B), JP1902.2 (B), JP1903.2 (B), JP1904.2 (B), JP1905.2 (B); also elsewhere on the board
unnamed: Channel14.9 (N/C), JP1901.1 (A)
unnamed: Channel14.10 (N/C), JP1902.1 (A)
unnamed: Channel14.11 (N/C), JP1903.1 (A)
unnamed: Channel14.13 (N/C), JP1904.1 (A)
unnamed: Channel14.15 (N/C), JP1905.1 (A)
VDrp14: Channel14.16 (UFETDrop); also elsewhere on the board
VShnt14: Channel14.12 (UCurrFlow); also elsewhere on the board

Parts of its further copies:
Channel0, Channel1, Channel2, Channel3, Channel4, Channel5, Channel6, Channel7, Channel8, Channel9, Channel10, Channel11, Channel12, Channel13, Channel15: ChannelShield
JP201, JP202, JP203, JP204, JP205, JP301, JP302, JP303, JP304, JP305, JP401, JP402, JP403, JP404, JP405, JP501, JP502, JP503, JP504, JP505, JP601, JP602, JP603, JP604, JP605, JP701, JP702, JP703, JP704, JP705, JP801, JP802, JP803, JP804, JP805, JP901, JP902, JP903, JP904, JP905, JP1001, JP1002, JP1003, JP1004, JP1005, JP1201, JP1202, JP1203, JP1204, JP1205, JP1501, JP1502, JP1503, JP1504, JP1505, JP1601, JP1602, JP1603, JP1604, JP1605, JP1701, JP1702, JP1703, JP1704, JP1705, JP1801, JP1802, JP1803, JP1804, JP1805, JP2001, JP2002, JP2003, JP2004, JP2005: Opt. GND; SolderJumper-2_P1.3mm_Open_RoundedPad1.0x1.5mm

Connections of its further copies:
+15V: Channel0.1 (+VSupply), Channel0.2 (+VSupply), Channel1.1 (+VSupply), Channel1.2 (+VSupply), Channel2.1 (+VSupply), Channel2.2 (+VSupply), Channel3.1 (+VSupply), Channel3.2 (+VSupply), Channel4.1 (+VSupply), Channel4.2 (+VSupply), Channel5.1 (+VSupply), Channel5.2 (+VSupply), Channel6.1 (+VSupply), Channel6.2 (+VSupply), Channel7.1 (+VSupply), Channel7.2 (+VSupply), Channel8.1 (+VSupply), Channel8.2 (+VSupply), Channel9.1 (+VSupply), Channel9.2 (+VSupply), Channel10.1 (+VSupply), Channel10.2 (+VSupply), Channel11.1 (+VSupply), Channel11.2 (+VSupply), Channel12.1 (+VSupply), Channel12.2 (+VSupply), Channel13.1 (+VSupply), Channel13.2 (+VSupply), Channel15.1 (+VSupply), Channel15.2 (+VSupply); also elsewhere on the board
-15V: Channel0.7 (-VSupply), Channel0.8 (-VSupply), Channel1.7 (-VSupply), Channel1.8 (-VSupply), Channel2.7 (-VSupply), Channel2.8 (-VSupply), Channel3.7 (-VSupply), Channel3.8 (-VSupply), Channel4.7 (-VSupply), Channel4.8 (-VSupply), Channel5.7 (-VSupply), Channel5.8 (-VSupply), Channel6.7 (-VSupply), Channel6.8 (-VSupply), Channel7.7 (-VSupply), Channel7.8 (-VSupply), Channel8.7 (-VSupply), Channel8.8 (-VSupply), Channel9.7 (-VSupply), Channel9.8 (-VSupply), Channel10.7 (-VSupply), Channel10.8 (-VSupply), Channel11.7 (-VSupply), Channel11.8 (-VSupply), Channel12.7 (-VSupply), Channel12.8 (-VSupply), Channel13.7 (-VSupply), Channel13.8 (-VSupply), Channel15.7 (-VSupply), Channel15.8 (-VSupply); also elsewhere on the board
DAC0: Channel0.14 (UCurrCtrl); also elsewhere on the board
DAC1: Channel1.14 (UCurrCtrl); also elsewhere on the board
DAC2: Channel2.14 (UCurrCtrl); also elsewhere on the board
DAC3: Channel3.14 (UCurrCtrl); also elsewhere on the board
DAC4: Channel4.14 (UCurrCtrl); also elsewhere on the board
DAC5: Channel5.14 (UCurrCtrl); also elsewhere on the board
DAC6: Channel6.14 (UCurrCtrl); also elsewhere on the board
DAC7: Channel7.14 (UCurrCtrl); also elsewhere on the board
DAC8: Channel8.14 (UCurrCtrl); also elsewhere on the board
DAC9: Channel9.14 (UCurrCtrl); also elsewhere on the board
DAC10: Channel10.14 (UCurrCtrl); also elsewhere on the board
DAC11: Channel11.14 (UCurrCtrl); also elsewhere on the board
DAC12: Channel12.14 (UCurrCtrl); also elsewhere on the board
DAC13: Channel13.14 (UCurrCtrl); also elsewhere on the board
DAC15: Channel15.14 (UCurrCtrl); also elsewhere on the board
GNDPWR: Channel0.3 (GND), Channel0.4 (GND), Channel0.5 (GND), Channel0.6 (GND), Channel1.3 (GND), Channel1.4 (GND), Channel1.5 (GND), Channel1.6 (GND), Channel2.3 (GND), Channel2.4 (GND), Channel2.5 (GND), Channel2.6 (GND), Channel3.3 (GND), Channel3.4 (GND), Channel3.5 (GND), Channel3.6 (GND), Channel4.3 (GND), Channel4.4 (GND), Channel4.5 (GND), Channel4.6 (GND), Channel5.3 (GND), Channel5.4 (GND), Channel5.5 (GND), Channel5.6 (GND), Channel6.3 (GND), Channel6.4 (GND), Channel6.5 (GND), Channel6.6 (GND), Channel7.3 (GND), Channel7.4 (GND), Channel7.5 (GND), Channel7.6 (GND), Channel8.3 (GND), Channel8.4 (GND), Channel8.5 (GND), Channel8.6 (GND), Channel9.3 (GND), Channel9.4 (GND), Channel9.5 (GND), Channel9.6 (GND), Channel10.3 (GND), Channel10.4 (GND), Channel10.5 (GND), Channel10.6 (GND), Channel11.3 (GND), Channel11.4 (GND), Channel11.5 (GND), Channel11.6 (GND), Channel12.3 (GND), Channel12.4 (GND), Channel12.5 (GND), Channel12.6 (GND), Channel13.3 (GND), Channel13.4 (GND), Channel13.5 (GND), Channel13.6 (GND), Channel15.3 (GND), Channel15.4 (GND), Channel15.5 (GND), Channel15.6 (GND), JP201.2 (B), JP202.2 (B), JP203.2 (B), JP204.2 (B), JP205.2 (B), JP301.2 (B), JP302.2 (B), JP303.2 (B), JP304.2 (B), JP305.2 (B), JP401.2 (B), JP402.2 (B), JP403.2 (B), JP404.2 (B), JP405.2 (B), JP501.2 (B), JP502.2 (B), JP503.2 (B), JP504.2 (B), JP505.2 (B), JP601.2 (B), JP602.2 (B), JP603.2 (B), JP604.2 (B), JP605.2 (B), JP701.2 (B), JP702.2 (B), JP703.2 (B), JP704.2 (B), JP705.2 (B), JP801.2 (B), JP802.2 (B), JP803.2 (B), JP804.2 (B), JP805.2 (B), JP901.2 (B), JP902.2 (B), JP903.2 (B), JP904.2 (B), JP905.2 (B), JP1001.2 (B), JP1002.2 (B), JP1003.2 (B), JP1004.2 (B), JP1005.2 (B), JP1201.2 (B), JP1202.2 (B), JP1203.2 (B), JP1204.2 (B), JP1205.2 (B), JP1501.2 (B), JP1502.2 (B), JP1503.2 (B), JP1504.2 (B), JP1505.2 (B), JP1601.2 (B), JP1602.2 (B), JP1603.2 (B), JP1604.2 (B), JP1605.2 (B), JP1701.2 (B), JP1702.2 (B), JP1703.2 (B), JP1704.2 (B), JP1705.2 (B), JP1801.2 (B), JP1802.2 (B), JP1803.2 (B), JP1804.2 (B), JP1805.2 (B), JP2001.2 (B), JP2002.2 (B), JP2003.2 (B), JP2004.2 (B), JP2005.2 (B); also elsewhere on the board
unnamed: Channel1.9 (N/C), JP201.1 (A)
unnamed: Channel1.10 (N/C), JP202.1 (A)
unnamed: Channel1.11 (N/C), JP203.1 (A)
unnamed: Channel1.13 (N/C), JP204.1 (A)
unnamed: Channel1.15 (N/C), JP205.1 (A)
unnamed: Channel2.9 (N/C), JP301.1 (A)
unnamed: Channel2.10 (N/C), JP302.1 (A)
unnamed: Channel2.11 (N/C), JP303.1 (A)
unnamed: Channel2.13 (N/C), JP304.1 (A)
unnamed: Channel2.15 (N/C), JP305.1 (A)
unnamed: Channel3.9 (N/C), JP401.1 (A)
unnamed: Channel3.10 (N/C), JP402.1 (A)
unnamed: Channel3.11 (N/C), JP403.1 (A)
unnamed: Channel3.13 (N/C), JP404.1 (A)
unnamed: Channel3.15 (N/C), JP405.1 (A)
unnamed: Channel4.9 (N/C), JP501.1 (A)
unnamed: Channel4.10 (N/C), JP502.1 (A)
unnamed: Channel4.11 (N/C), JP503.1 (A)
unnamed: Channel4.13 (N/C), JP504.1 (A)
unnamed: Channel4.15 (N/C), JP505.1 (A)
unnamed: Channel5.9 (N/C), JP601.1 (A)
unnamed: Channel5.10 (N/C), JP602.1 (A)
unnamed: Channel5.11 (N/C), JP603.1 (A)
unnamed: Channel5.13 (N/C), JP604.1 (A)
unnamed: Channel5.15 (N/C), JP605.1 (A)
unnamed: Channel6.9 (N/C), JP701.1 (A)
unnamed: Channel6.10 (N/C), JP702.1 (A)
unnamed: Channel6.11 (N/C), JP703.1 (A)
unnamed: Channel6.13 (N/C), JP704.1 (A)
unnamed: Channel6.15 (N/C), JP705.1 (A)
unnamed: Channel7.9 (N/C), JP801.1 (A)
unnamed: Channel7.10 (N/C), JP802.1 (A)
unnamed: Channel7.11 (N/C), JP803.1 (A)
unnamed: Channel7.13 (N/C), JP804.1 (A)
unnamed: Channel7.15 (N/C), JP805.1 (A)
unnamed: Channel8.9 (N/C), JP901.1 (A)
unnamed: Channel8.10 (N/C), JP902.1 (A)
unnamed: Channel8.11 (N/C), JP903.1 (A)
unnamed: Channel8.13 (N/C), JP904.1 (A)
unnamed: Channel8.15 (N/C), JP905.1 (A)
unnamed: Channel9.9 (N/C), JP1001.1 (A)
unnamed: Channel9.10 (N/C), JP1002.1 (A)
unnamed: Channel9.11 (N/C), JP1003.1 (A)
unnamed: Channel9.13 (N/C), JP1004.1 (A)
unnamed: Channel9.15 (N/C), JP1005.1 (A)
unnamed: Channel10.9 (N/C), JP1201.1 (A)
unnamed: Channel10.10 (N/C), JP1202.1 (A)
unnamed: Channel10.11 (N/C), JP1203.1 (A)
unnamed: Channel10.13 (N/C), JP1204.1 (A)
unnamed: Channel10.15 (N/C), JP1205.1 (A)
unnamed: Channel11.9 (N/C), JP1501.1 (A)
unnamed: Channel11.10 (N/C), JP1502.1 (A)
unnamed: Channel11.11 (N/C), JP1503.1 (A)
unnamed: Channel11.13 (N/C), JP1504.1 (A)
unnamed: Channel11.15 (N/C), JP1505.1 (A)
unnamed: Channel12.9 (N/C), JP1601.1 (A)
unnamed: Channel12.10 (N/C), JP1602.1 (A)
unnamed: Channel12.11 (N/C), JP1603.1 (A)
unnamed: Channel12.13 (N/C), JP1604.1 (A)
unnamed: Channel12.15 (N/C), JP1605.1 (A)
unnamed: Channel13.9 (N/C), JP1701.1 (A)
unnamed: Channel13.10 (N/C), JP1702.1 (A)
unnamed: Channel13.11 (N/C), JP1703.1 (A)
unnamed: Channel13.13 (N/C), JP1704.1 (A)
unnamed: Channel13.15 (N/C), JP1705.1 (A)
unnamed: Channel0.9 (N/C), JP1801.1 (A)
unnamed: Channel0.10 (N/C), JP1802.1 (A)
unnamed: Channel0.11 (N/C), JP1803.1 (A)
unnamed: Channel0.13 (N/C), JP1804.1 (A)
unnamed: Channel0.15 (N/C), JP1805.1 (A)
unnamed: Channel15.9 (N/C), JP2001.1 (A)
unnamed: Channel15.10 (N/C), JP2002.1 (A)
unnamed: Channel15.11 (N/C), JP2003.1 (A)
unnamed: Channel15.13 (N/C), JP2004.1 (A)
unnamed: Channel15.15 (N/C), JP2005.1 (A)
VDrp0: Channel0.16 (UFETDrop); also elsewhere on the board
VDrp1: Channel1.16 (UFETDrop); also elsewhere on the board
VDrp2: Channel2.16 (UFETDrop); also elsewhere on the board
VDrp3: Channel3.16 (UFETDrop); also elsewhere on the board
VDrp4: Channel4.16 (UFETDrop); also elsewhere on the board
VDrp5: Channel5.16 (UFETDrop); also elsewhere on the board
VDrp6: Channel6.16 (UFETDrop); also elsewhere on the board
VDrp7: Channel7.16 (UFETDrop); also elsewhere on the board
VDrp8: Channel8.16 (UFETDrop); also elsewhere on the board
VDrp9: Channel9.16 (UFETDrop); also elsewhere on the board
VDrp10: Channel10.16 (UFETDrop); also elsewhere on the board
VDrp11: Channel11.16 (UFETDrop); also elsewhere on the board
VDrp12: Channel12.16 (UFETDrop); also elsewhere on the board
VDrp13: Channel13.16 (UFETDrop); also elsewhere on the board
VDrp15: Channel15.16 (UFETDrop); also elsewhere on the board
VShnt0: Channel0.12 (UCurrFlow); also elsewhere on the board
VShnt1: Channel1.12 (UCurrFlow); also elsewhere on the board
VShnt2: Channel2.12 (UCurrFlow); also elsewhere on the board
VShnt3: Channel3.12 (UCurrFlow); also elsewhere on the board
VShnt4: Channel4.12 (UCurrFlow); also elsewhere on the board
VShnt5: Channel5.12 (UCurrFlow); also elsewhere on the board
VShnt6: Channel6.12 (UCurrFlow); also elsewhere on the board
VShnt7: Channel7.12 (UCurrFlow); also elsewhere on the board
VShnt8: Channel8.12 (UCurrFlow); also elsewhere on the board
VShnt9: Channel9.12 (UCurrFlow); also elsewhere on the board
VShnt10: Channel10.12 (UCurrFlow); also elsewhere on the board
VShnt11: Channel11.12 (UCurrFlow); also elsewhere on the board
VShnt12: Channel12.12 (UCurrFlow); also elsewhere on the board
VShnt13: Channel13.12 (UCurrFlow); also elsewhere on the board
VShnt15: Channel15.12 (UCurrFlow); also elsewhere on the board

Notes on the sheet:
Regulation-Channels designed externally as a modular shield
N/C got Jumpers to GND connected so that there is the possibility to disconnect the pins from GND and use flying wires to connect something else (if necessary!)
Regularly they should be closed, but it's faster and more easy, by closing them by soldering as it is when they need to be opened by cutting them with a scalpell when the GND-connection is unwanted!

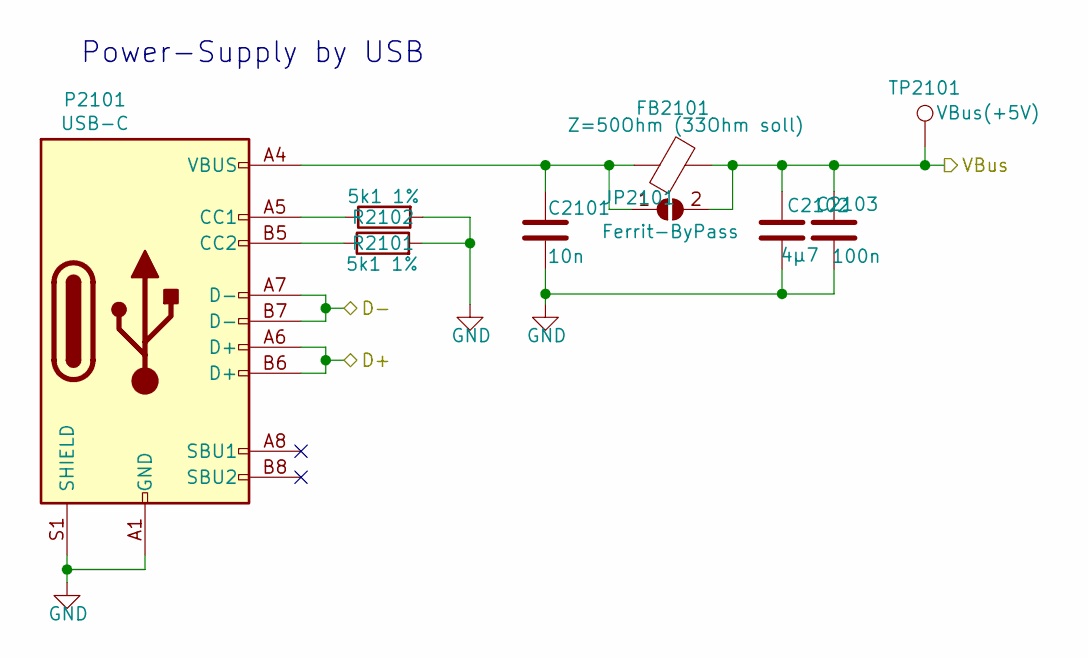
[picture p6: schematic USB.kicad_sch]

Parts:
C2101: 10n; C_0603_1608Metric
C2102: 4µ7; CP_EIA-3528-21_Kemet-B
C2103: 100n; C_0603_1608Metric
FB2101: Z=50Ohm (33Ohm soll); L_1206_3216Metric
JP2101: Ferrit-ByPass; SolderJumper-2_P1.3mm_Open_RoundedPad1.0x1.5mm
P2101: USB-C; USB_C_Receptacle_HRO_TYPE-C-31-M-12
R2101, R2102: 5k1 1%; R_0603_1608Metric
TP2101: VBus(+5V); TestPoint_Pad_D1.5mm

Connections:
D+: P2101.A6 (D+), P2101.B6 (D+); also elsewhere on the board
D-: P2101.A7 (D-), P2101.B7 (D-); also elsewhere on the board
GND: C2101.2, C2102.2, C2103.2, P2101.A1 (GND), P2101.A12 (GND), P2101.B1 (GND), P2101.B12 (GND), P2101.S1 (SHIELD), R2101.2, R2102.2; also elsewhere on the board
unnamed: C2101.1, FB2101.1, JP2101.1 (A), P2101.A4 (VBUS), P2101.A9 (VBUS), P2101.B4 (VBUS), P2101.B9 (VBUS)
unnamed: P2101.A5 (CC1), R2102.1
unnamed: P2101.B5 (CC2), R2101.1
VBUS (5V): C2102.1, C2103.1, FB2101.2, JP2101.2 (B), TP2101.1; also elsewhere on the board

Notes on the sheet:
Power-Supply by USB

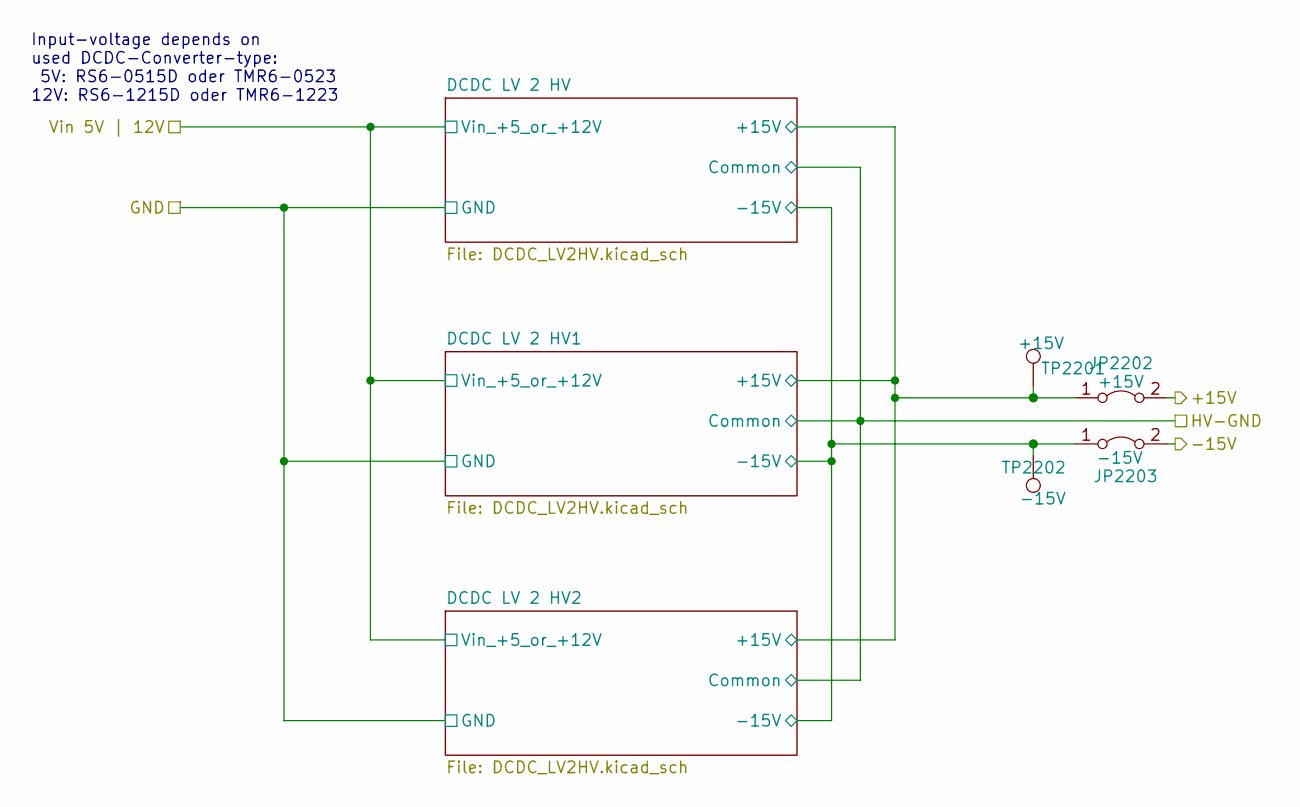
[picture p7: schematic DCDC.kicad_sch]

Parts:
JP2202: +15V; PinHeader_1x02_P2.54mm_Vertical
JP2203: -15V; PinHeader_1x02_P2.54mm_Vertical
TP2201: +15V; TestPoint_Pad_D1.5mm
TP2202: -15V; TestPoint_Pad_D1.5mm

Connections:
+15V: JP2202.2 (B); also elsewhere on the board
-15V: JP2203.2 (B); also elsewhere on the board
/DCDC PC -> HV-Reg/DCDC LV 2 HV/+15V: JP2202.1 (A), TP2201.1; also elsewhere on the board
/DCDC PC -> HV-Reg/DCDC LV 2 HV/-15V: JP2203.1 (A), TP2202.1; also elsewhere on the board

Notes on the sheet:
Input-voltage depends on used DCDC-Converter-type: 5V: RS6-0515D oder TMR6-0523 12V: RS6-1215D oder TMR6-1223

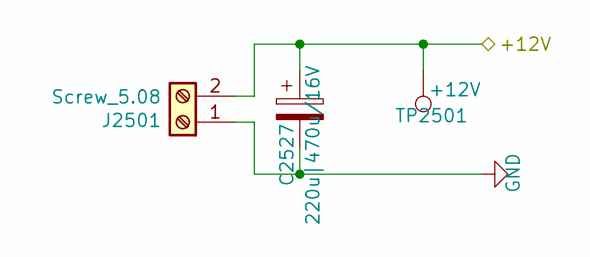
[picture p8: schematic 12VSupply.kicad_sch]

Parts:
C2527: 220u|470u/16V; CP_Elec_10x10.5
J2501: Screw_5.08; TerminalBlock_RND_205-00232_1x02_P5.08mm_Horizontal
TP2501: +12V; TestPoint_Pad_D1.5mm

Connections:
GND: C2527.2, J2501.1; also elsewhere on the board
Vin_12V: C2527.1, J2501.2, TP2501.1; also elsewhere on the board

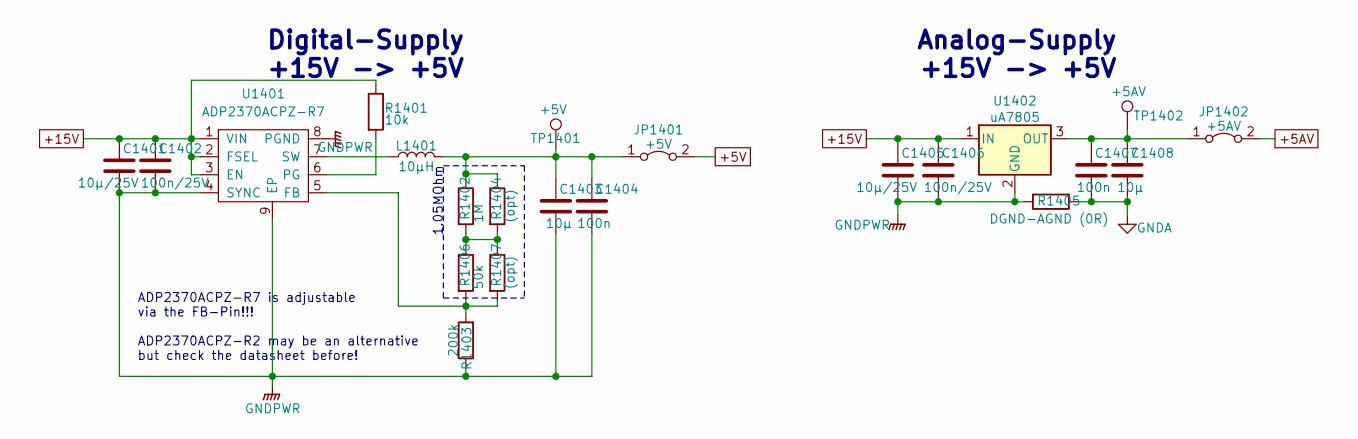
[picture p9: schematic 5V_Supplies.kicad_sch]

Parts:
C1401, C1405: 10µ/25V; C_0805_2012Metric
C1402, C1406: 100n/25V; C_0603_1608Metric
C1403, C1408: 10µ; C_0805_2012Metric
C1404, C1407: 100n; C_0603_1608Metric
JP1401: +5V; PinHeader_1x02_P2.54mm_Vertical
JP1402: +5AV; PinHeader_1x02_P2.54mm_Vertical
L1401: 10µH; L_Coilcraft_XxL4040
R1401: 10k; R_0603_1608Metric
R1402: 1M; R_0603_1608Metric
R1403: 200k; R_0603_1608Metric
R1404, R1407: (opt); R_0603_1608Metric
R1405: DGND-AGND (0R); R_0603_1608Metric
R1406: 50k; R_0603_1608Metric
TP1401: +5V; TestPoint_Pad_D1.5mm
TP1402: +5AV; TestPoint_Pad_D1.5mm
U1401: ADP2370ACPZ-R7; LFCSP-8-1EP_3x3mm_P0.5mm_EP1.6x2.34mm_ThermalVias
U1402: uA7805; SOT-223-3_TabPin2

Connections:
+5AV: JP1402.2 (B); also elsewhere on the board
+5V: JP1401.2 (B); also elsewhere on the board
+15V: C1401.1, C1402.1, C1405.1, C1406.1, R1401.1, U1401.1 (VIN), U1401.2 (FSEL), U1401.3 (EN), U1402.1 (IN); also elsewhere on the board
GNDA: C1407.2, C1408.2, R1405.1; also elsewhere on the board
GNDPWR: C1401.2, C1402.2, C1403.2, C1404.2, C1405.2, C1406.2, R1403.1, R1405.2, U1401.4 (SYNC), U1401.8 (PGND), U1401.9 (EP), U1402.2 (GND); also elsewhere on the board
unnamed: C1403.1, C1404.1, JP1401.1 (A), L1401.2, R1402.1, R1404.1, TP1401.1
unnamed: C1407.1, C1408.1, JP1402.1 (A), TP1402.1, U1402.3 (OUT)
unnamed: R1402.2, R1404.2, R1406.1, R1407.1
unnamed: R1403.2, R1406.2, R1407.2, U1401.5 (FB)
unnamed: R1401.2, U1401.6 (PG)
unnamed: L1401.1, U1401.7 (SW)

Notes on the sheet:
1.05MOhm
Digital-Supply +15V -> +5V
ADP2370ACPZ-R7 is adjustable via the FB-Pin!!! ADP2370ACPZ-R2 may be an alternative but check the datasheet before!
Analog-Supply +15V -> +5V

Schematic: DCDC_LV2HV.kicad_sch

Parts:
C2104: 10µ/16V; C_0805_2012Metric
C2105: 100n/16V; C_0603_1608Metric
C2106: 10µ/25V; C_0805_2012Metric
C2107: 10µF/25V; C_0805_2012Metric
C2108, C2109: 100n/25V; C_0603_1608Metric
D2101, D2102: BAT54(W); SOT-323_SC-70
PS2101: 5V/12V -> +-15V DCDC; TMR_6-0523

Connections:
/DCDC PC -> HV-Reg/DCDC LV 2 HV/+15V: D2101.3 (K); also elsewhere on the board
/DCDC PC -> HV-Reg/DCDC LV 2 HV/-15V: D2102.1 (A); also elsewhere on the board
/DCDC PC -> HV-Reg/Vin 5V | 12V: C2104.2, C2105.1, PS2101.2 (+VIN); also elsewhere on the board
GND: C2104.1, C2105.2, PS2101.1 (-VIN); also elsewhere on the board
GNDPWR: C2106.1, C2107.2, C2108.2, C2109.1, PS2101.7 (Common); also elsewhere on the board
unnamed: C2106.2, C2108.1, D2101.1 (A), PS2101.6 (+VOUT)
unnamed: C2107.1, C2109.2, D2102.3 (K), PS2101.8 (-VOUT)

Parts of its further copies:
C2227, C2601: 10µ/16V; C_0805_2012Metric
C2228, C2602: 100n/16V; C_0603_1608Metric
C2229, C2603: 10µ/25V; C_0805_2012Metric
C2230, C2604: 10µF/25V; C_0805_2012Metric
C2231, C2232, C2605, C2606: 100n/25V; C_0603_1608Metric
D2201, D2202, D2601, D2602: BAT54(W); SOT-323_SC-70
PS2201, PS2601: 5V/12V -> +-15V DCDC; TMR_6-0523

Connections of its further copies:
/DCDC PC -> HV-Reg/DCDC LV 2 HV/+15V: D2201.3 (K), D2601.3 (K); also elsewhere on the board
/DCDC PC -> HV-Reg/DCDC LV 2 HV/-15V: D2202.1 (A), D2602.1 (A); also elsewhere on the board
/DCDC PC -> HV-Reg/Vin 5V | 12V: C2227.2, C2228.1, C2601.2, C2602.1, PS2201.2 (+VIN), PS2601.2 (+VIN); also elsewhere on the board
GND: C2227.1, C2228.2, C2601.1, C2602.2, PS2201.1 (-VIN), PS2601.1 (-VIN); also elsewhere on the board
GNDPWR: C2229.1, C2230.2, C2231.2, C2232.1, C2603.1, C2604.2, C2605.2, C2606.1, PS2201.7 (Common), PS2601.7 (Common); also elsewhere on the board
unnamed: C2229.2, C2231.1, D2201.1 (A), PS2201.6 (+VOUT)
unnamed: C2230.1, C2232.2, D2202.3 (K), PS2201.8 (-VOUT)
unnamed: C2603.2, C2605.1, D2601.1 (A), PS2601.6 (+VOUT)
unnamed: C2604.1, C2606.2, D2602.3 (K), PS2601.8 (-VOUT)

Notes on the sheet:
Input-voltage depends on used DCDC-Converter-type: 5V: RS6-0515D oder TMR6-0523 12V: RS6-1215D oder TMR6-1223

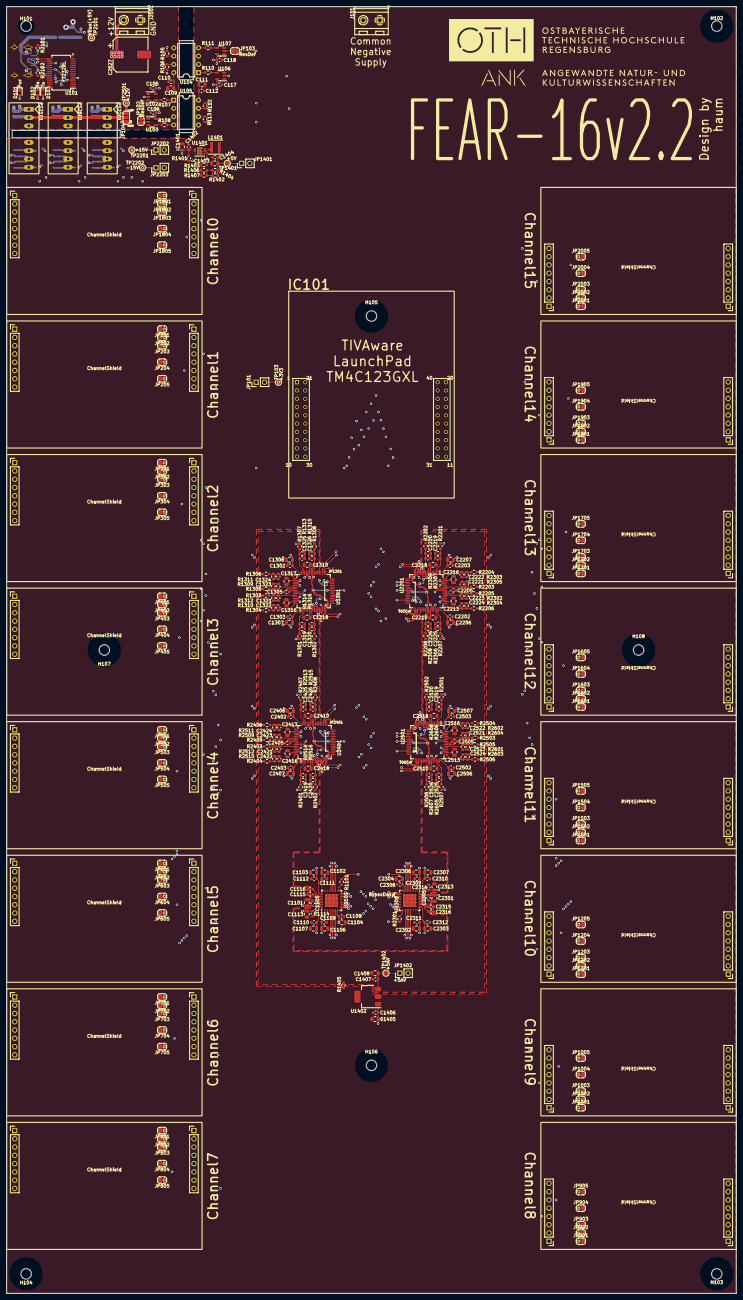
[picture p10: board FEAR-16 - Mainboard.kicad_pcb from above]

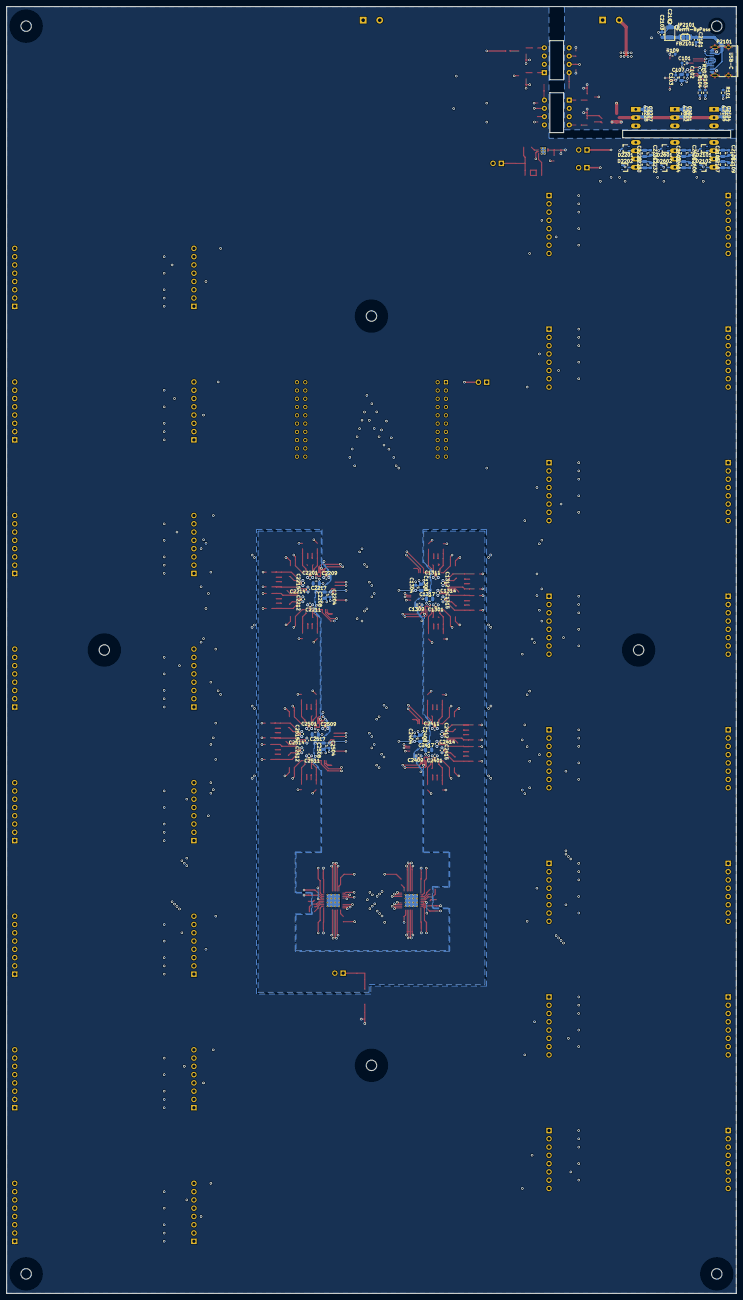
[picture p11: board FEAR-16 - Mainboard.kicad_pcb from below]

Board: 4 copper layers, 224.0 x 395.0 mm, 423 parts (75 on the bottom side), 266 nets.

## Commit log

2023-07-20 FEAR-16 V2.2
    PCB-Changes:
    - Added rudimentary "load-balancer" (not really a balancer, but should avoid the DC/DC from regulating against each other!)
    - Added optional GND-jumpers to the N/C pins of the shields
    - Modified amplification adjustment:
    -> Added a offset resistor in row to the trim-poti for amplification for finer amp-tuning
    -> Reduced trim-poti-value from 1Meg -> 50k (20x finer adjustment-range)
    Poti can in the range of:
    - 30k (min) for being able to reach the correct amplification
    - 50k (max) for having at least 20x finer tune-range and a bit of reserve, as 30k is pretty thight on tolerance
    Misc.:
    - Added LICENSE.md
    [12VSupply.kicad_sch, 5V_Supplies.kicad_sch, ADS8568.kicad_sch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]
2024-08-07 Fixed ADP2370 designator
    ADP2370 has a bunch of fixed output voltages and an adjustable model.
    We use the adjustable model, so we fixed the name matching with the correct model-name.
    [12VSupply.kicad_sch, 5V_Supplies.kicad_sch, ADS8568.kicad_sch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]
2024-09-13 Finished README.md
    - Adjustment in .gitignore
    - Finished first README.md attempt
    - Added extra comments to "5V_Supplies"
    [5V_Supplies.kicad_sch, FEAR-16 - Mainboard.kicad_sch, USB.kicad_sch]
